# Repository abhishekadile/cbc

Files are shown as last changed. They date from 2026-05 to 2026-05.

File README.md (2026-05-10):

# Multispectral CBC Image Acquisition System

This is a complete full-stack embedded systems project for capturing multispectral CBC (Complete Blood Count) imagery using a Raspberry Pi and an InnovaMaker IMX296 global shutter camera. 

> **Disclaimer:** This is a prototype/research image acquisition system. It does not provide medical diagnosis and is not for clinical use. An AI analysis module is planned for future versions.

## 🚀 Features
- **Hardware Integration**: Controls InnovaMaker IMX296 MIPI global shutter camera.
- **Data Management**: Robust directory structure for scan sessions ensuring no lost data.
- **User Interface**: Modern React/Vite-based investor demo dashboard.
- **Extensibility**: Hardware Abstraction Layers (HAL) for future microcontrollers, XY stages, Z focus actuators, and multispectral LED channels.

## 📦 Supported Hardware
- **Current**: Raspberry Pi + InnovaMaker IMX296 MIPI camera
- **Planned**: XY Stage, Z Focus Actuator, Multispectral LED Channels, RP2040/STM32 timing controller

---

## 🛠️ Step-by-Step Setup Guide for Raspberry Pi

Follow these exact steps to set up the software on a fresh Raspberry Pi.

### 1. Initial Raspberry Pi Configuration
1. Flash standard **Raspberry Pi OS (64-bit)** to an SD card using the Raspberry Pi Imager.
2. Boot the Pi, connect it to your local Wi-Fi, and enable SSH.
3. Connect the InnovaMaker IMX296 FPC cable to the CSI port on the Raspberry Pi.
4. Open the boot configuration file to enable the camera overlay:
   ```bash
   sudo nano /boot/firmware/config.txt
   ```
5. Add the following line at the end of the file:
   ```text
   dtoverlay=imx296
   ```
6. Save (`Ctrl+O`, `Enter`) and exit (`Ctrl+X`), then reboot:
   ```bash
   sudo reboot
   ```

### 2. Verify Hardware with Libcamera
After rebooting, test that the system recognizes the camera and the driver is loaded using the standard Raspberry Pi tools:
```bash
rpicam-hello -t 5000
rpicam-still -o test.jpg
```

### 2. Software Installation
Once the Pi has rebooted, open a terminal (or SSH into it) and run the one-line bootstrap script. This script will install Git, curl, uv (Python dependency manager), clone this repository, and install all required system and frontend dependencies.

```bash
curl -fsSL https://raw.githubusercontent.com/abhishekadile/cbc/main/scripts/bootstrap_pi.sh | bash
```

Alternatively, you can install manually:
```bash
git clone https://github.com/abhishekadile/cbc.git ~/cbc-scanner
cd ~/cbc-scanner
bash scripts/install_pi.sh
```

---

## 💻 Running the Application

### Starting the Main Interface (UI + Backend)
To run the full stack (FastAPI backend + Vite React frontend) locally on the Pi:
```bash
cd ~/cbc-scanner
bash scripts/run_ui.sh
```
Once running, open a web browser on your laptop or Pi and navigate to:
**`http://localhost:8000`** (or use the Pi's actual IP address).

### Testing the REST API
You can verify the backend is running properly via the terminal:
```bash
curl http://localhost:8000/api/devices/status
curl -X POST http://localhost:8000/api/camera/test
curl -X POST http://localhost:8000/api/capture/single
curl http://localhost:8000/api/scans
```

### Running as a Background Service (Auto-start on Boot)
If you want the software to run automatically every time the Pi turns on:
```bash
cd ~/cbc-scanner
bash scripts/create_systemd_service.sh
sudo systemctl enable cbc-scanner
sudo systemctl start cbc-scanner
```

---

## 🔬 Command Line Utilities

We provide several command-line tools for debugging and manual control. All commands should be run from the `~/cbc-scanner` directory using `uv run`.

**1. Test Camera Connection**
Verifies that the IMX296 camera is properly detected and can be communicated with via Picamera2.
```bash
cd ~/cbc-scanner
uv run cbc-test-camera
```

**2. Capture a Single Image**
Captures exactly one image and saves it in a new scan session.
```bash
cd ~/cbc-scanner
uv run cbc-capture
```

**3. Run a Demo Multispectral Scan**
Simulates a full multispectral acquisition loop. It captures frames representing 5 wavelengths (White, 405nm, 530nm, 660nm, 850nm). *Note: until the LED board is connected, these use the ambient lighting.*
```bash
cd ~/cbc-scanner
uv run cbc-demo-scan
```

**4. Check Storage Info**
Displays the local storage base directory and a table of recently acquired scans.
```bash
cd ~/cbc-scanner
uv run cbc-storage-info
```

---

## 🔄 Updating the Software
To pull the latest changes from this GitHub repository and rebuild the environment:
```bash
cd ~/cbc-scanner
bash scripts/update_from_github.sh
```

---

## 📂 Data Storage Format
Images and scan metadata are never overwritten. They are stored chronologically in:
`data/scans/YYYY/MM/DD/scan_YYYYMMDD_HHMMSS_ID/`

Each scan directory contains:
- `raw/`: Raw, unprocessed `.png` image captures.
- `thumbnails/`: Downsampled images for the UI dashboard.
- `stitched/`: Future location for multi-grid panoramas.
- `metadata/manifest.json`: Device status, time, hardware profile, and exposure data.
- `logs/`: Diagnostic logs specific to the scan.

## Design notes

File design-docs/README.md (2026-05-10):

# CBC Multispectral Imaging System Design Documentation

This is a research and engineering prototype for a multispectral CBC image acquisition system. It is not for diagnosis, treatment, or clinical use.

## Folder Structure Guide

This documentation is organized into four main pillars that map directly to the system's architecture and development lifecycle:

### 1. `hardware/`
Contains the physical design of the CBC scanner. It is split into two tracks:
- **`prototype/`**: Focuses on rapid iteration. It details the 3D-printing strategy, manual assembly guides, and off-the-shelf components required to build the first functional unit. The goal here is proving the optical path and software integration.
- **`production/`**: Focuses on reliability and scaling. It outlines the transition to rigid materials, precision linear guides, and the engineering requirements for a known-volume fluid cartridge necessary for absolute cell concentration calculations.

### 2. `embedded-software/`
Details the software running directly on the hardware (the Raspberry Pi). This folder covers:
- The tech stack (Python, FastAPI, `uv`, `libcamera`/`Picamera2`).
- How the device orchestrates the capture sequence, including multispectral LED synchronization and motor control.
- The precise data schema (`manifest.json`) used to package images and metadata into a "Scan Session" before sending it to the cloud or AI pipeline.

### 3. `AI/`
Outlines the entire data science and machine learning workstream. This is the brain of the system, responsible for counting and classifying cells:
- **Model Strategy**: Deciding which architectures to use (e.g., YOLO11-seg for detection, U-Net for precise segmentation, EfficientNet for classification).
- **Pretraining & Data**: How public datasets are used to bootstrap models before fine-tuning on device-specific images.
- **Computer Vision (CV) Pipeline**: The classical algorithms (thresholding, watershed) used for immediate object detection, image quality control, and generating pseudo-labels.
- **Labeling & Evaluation**: The strict workflow for human-in-the-loop annotation and the statistical metrics used to prove accuracy.

### 4. `cloud/`
Describes the off-device architecture needed to scale the project. While the scanner is designed to be "local-first," this folder covers:
- **Data Management**: How scan sessions are securely uploaded and stored in object storage (e.g., S3).
- **Fleet & Model Registries**: Tracking active devices in the field and managing over-the-air updates for newly trained AI models.
- **Experiment Tracking**: The infrastructure (like MLflow) used by researchers to track model training runs and dataset versions.

## Build Phases

The project will follow these sequential build phases:

1. **Prototype imaging system**: Build the initial 3D-printed hardware, integrate the IMX296 camera, and establish basic control.
2. **CV-first segmentation**: Implement classical computer vision to detect objects and create pseudo-labels.
3. **AI pretraining and fine-tuning**: Pretrain models on public datasets and fine-tune on device-captured images.
4. **Hybrid AI/CV pipeline**: Integrate both approaches for robust counting and quality control.
5. **Production hardware and cartridge**: Transition to a rigid frame, controlled cartridge, and repeatable optical path.
6. **Cloud scaling and data management**: Implement cloud uploads, scan dashboards, and a model registry.

## Prototype Goals

The first prototype goal is *not* clinical accuracy. The initial objectives are to:
- capture clear microscope images
- capture 5 to 10 overlapping images
- stitch them together
- segment visible objects
- count objects
- create a dataset loop
- compare CV counts, AI counts, and reviewed labels

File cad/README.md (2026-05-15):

# CBC Microscope Prototype CAD

This `cad/` system contains Fusion-oriented Python scripts for the custom printed parts and simplified assemblies for the CBC microscope prototype.

Design policy:

- Bought precision parts stay bought: optics, rails, lead screws/nuts, boards, screws, inserts, motors, and drivers.
- Printed parts are modular bolt-together components, not a monolithic frame.
- Manual XY is the first assembly variant; NEMA17 motorized XY is optional.
- The optical datum is the sensor plane. For the finite objective path, objective shoulder to sensor plane is held at `160.0 mm`.
- Unresolved vendor geometry remains parameterized and uses slots or placeholders.
- No arbitrary shell execution, subprocess command runner, or network code is present in this CAD tree.

Key commands from the repo root:

```powershell
python -m cad.scripts.tools.build_all_parts
python -m cad.scripts.tools.build_all_assemblies
python -m cad.scripts.tools.build_stage1
python -m pytest cad/tests
```

`build_all_parts`, `build_all_assemblies`, and `build_stage1` are safe offline commands. They build deterministic specs/reports and do not create manufacturing STL/STEP files outside Fusion.

Fusion bridge smoke tests assume the existing local MCP/Fusion bridge is active at:

```text
http://127.0.0.1:8765
```

Stage 1 generated naming follows:

- Native assembly: `cbc_stage1_static_optical_stack_r001.f3d`
- STEP part: `cbc_slide_holder_r001.step`
- STL part: `cbc_slide_holder_r001.stl`

## Real Fusion Exports vs Offline Specs

Only files generated inside Autodesk Fusion through `ExportManager` should be treated as printable/manufacturing CAD.

Offline Python runs may write deterministic `.non_printable_spec.json` files for validation and CI. Those files are not STL/STEP manufacturing outputs.

The first real printable Fusion part implemented is:

```powershell
python -m cad.scripts.parts.cbc_slide_holder
```

Run that command from Fusion's Python environment, or run the script through Fusion's Scripts and Add-Ins workflow. When Fusion is live, it creates a separate component/body named `cbc_slide_holder_r001` and exports:

- `cad/exports/stl/cbc_slide_holder_r001.stl`
- `cad/exports/step/cbc_slide_holder_r001.step`

When run outside Fusion, the same command writes only a non-printable JSON spec and does not claim to create printable CAD.

For the full Stage 1 export set, run this from Fusion's Python environment:

```powershell
python -m cad.scripts.tools.export_stage1
```

Outside Fusion, `export_stage1` and `export_all` refuse with a `RuntimeError` and do not write placeholder manufacturing files.

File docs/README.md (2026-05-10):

# CBC Project Documentation Guide

This `docs/` folder organizes the project into four workstreams:

1. **Hardware** - mechanical, optical, motion, cartridge, and production design.
2. **Embedded Software** - Raspberry Pi, camera control, LED control, motion control, and device orchestration.
3. **AI** - model pretraining, dataset organization, computer vision, and final AI/CV pipeline.
4. **Cloud** - storage, APIs, dashboards, training infrastructure, model registry, and future remote device management.

The root `README.md` should remain the quick-start guide for running the current repo. This folder is for deeper engineering plans, design decisions, and implementation roadmaps.

## Folder structure

```text
docs/
  README.md
  hardware/
    README.md
    prototype/
      README.md
      prototype-spec.md
      prototype-product-list.md
    production/
      README.md
      production-spec.md
      production-product-list.md
  embedded-software/
    README.md
  AI/
    README.md
    01-model-strategy.md
    02-pretraining-plan.md
    03-computer-vision-system.md
    04-final-ai-cv-pipeline.md
  cloud/
    README.md
```

## Build order

### Phase 1: Prototype imaging system

Goal: prove that the device can capture clear microscope images, capture a small number of overlapping fields, and stitch 5 to 10 images together.

Primary docs:

- `hardware/prototype/prototype-spec.md`
- `hardware/prototype/prototype-product-list.md`
- `embedded-software/README.md`
- `AI/03-computer-vision-system.md`

### Phase 2: AI dataset and pretraining

Goal: prepare public datasets, normalize labels, train a pretrained image model on blood-cell microscopy data, and fine-tune with images captured from this device.

Primary docs:

- `AI/01-model-strategy.md`
- `AI/02-pretraining-plan.md`

### Phase 3: Hybrid CV plus neural model

Goal: use classical computer vision to generate candidate masks, coordinates, and pseudo-labels, then use reviewed labels to train the neural model.

Primary docs:

- `AI/03-computer-vision-system.md`
- `AI/04-final-ai-cv-pipeline.md`

### Phase 4: Production hardware direction

Goal: evolve from a mostly 3D-printed prototype to a controlled cartridge, more rigid optical path, calibrated motion, and repeatable image acquisition.

Primary docs:

- `hardware/production/production-spec.md`
- `hardware/production/production-product-list.md`

### Phase 5: Cloud and scaling

Goal: support remote data upload, experiment tracking, model registry, training jobs, dashboarding, and future device fleet management.

Primary docs:

- `cloud/README.md`

## Current principle

The first milestone is not clinical CBC accuracy. The first milestone is engineering validation:

- capture clear images,
- capture multiple nearby images,
- stitch fields together,
- segment visible cell-like objects,
- create a repeatable dataset loop,
- compare CV counts, model counts, and reviewed labels.

This project is a research and engineering prototype. It is not for diagnosis, treatment, or clinical decision-making.

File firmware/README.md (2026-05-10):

# Firmware

This directory will contain the C/C++ firmware for the future timing controller (e.g., STM32, RP2040) used to control the XY stage, Z focus, and multispectral LEDs.

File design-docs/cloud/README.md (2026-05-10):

# Cloud Architecture

This document describes the cloud infrastructure required to scale data collection, manage a fleet of prototype devices, and orchestrate model training.

*Important Note: This is an engineering prototype system. There are no clinical use claims. The data handled is for research and development purposes only. However, future architectures will need to observe HIPAA guidelines if transitioning to human clinical trials.*

## System Philosophy

- **Local-first system**: The scanner must be capable of completing a scan, running local CV preprocessing, and saving data without an active internet connection. The cloud is an enhancement, not a strict dependency for operation.
- **Optional cloud sync**: When connected to Wi-Fi, the device can background-upload scan sessions to cloud storage.

## Key Components

- **Storage**: Highly scalable object storage for millions of raw TIFF/JPEG images.
- **Dashboard**: A web portal for engineers and researchers to view uploaded scans, verify image quality, and manage devices.
- **Training Data Repository**: A centralized, version-controlled repository where data is formatted for PyTorch/Ultralytics consumption.
- **Experiment Tracking**: A central server logging loss curves, metrics, and configs for every AI training run.
- **Model Registry**: A version-controlled storage bin for compiled AI models (`.pt`, `.onnx`, or `.tflite`).
- **Device Registry**: A database tracking every active scanner in the field, its MAC address, current IP, hardware version, and deployed model version.
- **Access Control**: Role-Based Access Control (RBAC) ensuring only authorized engineers can trigger remote updates or access datasets.
- **Security**: TLS for all API traffic, signed URLs for direct-to-storage image uploads.

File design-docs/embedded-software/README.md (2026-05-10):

# Embedded Software

The embedded software runs on the Raspberry Pi and acts as the brain of the acquisition hardware. It orchestrates the camera, the lighting, the motion stage, and the data packaging.

## Core Responsibilities

- **Raspberry Pi as Acquisition Controller**: The Pi handles all high-level scheduling, file system operations, and network communication.
- **Camera Control**: Interfaces with the IMX296 sensor via `Picamera2` or `libcamera`, configuring exposure, gain, and format.
- **LED Control**: Toggles GPIO pins to control the multispectral LED array, ensuring the correct wavelength is active during exposure.
- **Future XY/Z Motion Control**: Interfaces with stepper motor drivers (via GPIO or I2C) to move the stage for stitching and adjust focus.
- **Scan Session Manager**: Orchestrates the multi-step process of capturing a full slide (move stage -> set LED -> capture -> next wavelength -> next position).
- **REST API**: Exposes endpoints (via FastAPI) to start, stop, and configure scans.
- **Local UI**: Serves a local React dashboard for the user operating the machine.
- **Metadata**: Collects hardware state (temperature, exposure settings) and packages it with the images.
- **Logs**: Maintains detailed diagnostic logs for troubleshooting.

## Future Microcontroller Option
As the system scales to closed-loop motors and microsecond-level LED pulsing, the Raspberry Pi's non-real-time Linux OS may introduce jitter. Future architectures will delegate real-time hardware IO to an attached microcontroller (like an RP2040 or STM32), which will communicate with the Pi via Serial/I2C.

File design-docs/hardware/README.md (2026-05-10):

# Hardware Architecture

The CBC scanner hardware is designed to evolve from an accessible, easily iteratable 3D-printed prototype to a robust, precisely calibrated production system.

## System Purpose
The primary purpose of the hardware is to acquire high-resolution, multispectral images of biological samples (specifically blood cells) with sufficient clarity and consistency to enable automated computer vision and AI-based counting/classification.

## Prototype vs. Production Philosophy
- **Prototype**: Focuses on accessibility, rapid iteration, and software integration. It uses off-the-shelf components, standard microscope slides, and 3D-printed brackets where possible. The primary goal is capturing 5-10 overlapping images to prove the stitching and baseline segmentation pipeline.
- **Production**: Focuses on stability, repeatability, and quantitative accuracy. It will transition to a rigid chassis (sheet metal/machined aluminum), precision linear guides, and a custom *known-volume* cartridge necessary for calculating absolute cell concentrations.

## Subsystem Descriptions

- **Optics**: A compound microscope optical path utilizing standard objectives (e.g., 10X or 40X Plan Achromatic) to achieve the necessary magnification and flat field of view.
- **Camera**: Raspberry Pi acting as the host for an InnovaMaker IMX296 global shutter camera. Global shutter is critical to prevent motion blur during continuous scanning or under pulsed illumination.
- **Illumination**: A multispectral LED array (e.g., 405nm, 470nm, 530nm, 660nm) coupled with a diffuser to provide uniform transmitted or reflected light.
- **Slide/Cartridge Holder**: A mechanical stage to securely hold the sample. The prototype uses standard glass slides; production will use a custom cartridge.
- **XY Stage**: Enables scanning across the sample. The prototype uses metal rods/rails; production will use high-precision linear guides.
- **Z Focus**: Adjusts focus depth, utilizing a lead screw or fine-pitch threaded rod driven by a stepper motor.
- **Frame/Enclosure**: The structural backbone. Must block ambient light to ensure controlled multispectral capture.
- **Raspberry Pi/Electronics Mount**: Secures the compute module, motor drivers, and power distribution securely away from the optical path to manage heat.
- **Cable Routing**: Cable chains or clips to route the MIPI camera ribbon cable and motor wires, preventing snagging during stage movement.
- **Power**: A centralized power supply (e.g., 12V or 24V for motors, stepped down to 5V for the Raspberry Pi).
- **Calibration Tools**: Stage micrometers and calibration slides for mapping pixel dimensions to physical microns.

## System Block Diagram

```mermaid
flowchart LR
    LED[Multispectral LED Array] --> Diffuser[Diffuser]
    Diffuser --> Sample[Slide / Cartridge]
    Sample --> Optics[Objective / Tube Lens]
    Optics --> Camera[IMX296 Camera]
    Camera --> RPi[Raspberry Pi]
    RPi --> Storage[Local Storage / API]
    Storage --> Pipeline[AI/CV Pipeline]
```

## Mechanical Stack Diagram

```mermaid
flowchart TD
    Camera[Camera Mount] --> Optics[Optics Mount / Z-Axis]
    Optics --> Base[Main Frame]
    Sample[Slide Holder / XY Stage] --> Base
    Illumination[LED / Diffuser Mount] --> Base
```

## Assumptions
- The prototype uses normal microscope slides initially.
- The final cartridge will be engineered later.
- The prototype only needs to capture 5 to 10 overlapping images and stitch them.
- The final system will use a known volume for concentration calculations.

## Engineering Risks
- **Blur**: From external vibrations or internal motor resonances. Mitigation: Dampening feet, global shutter.
- **Poor Focus**: Drift in the Z-axis. Mitigation: Anti-backlash nuts, rigid Z-carriage.
- **Vibration**: Camera shutter or fan causing micro-vibrations.
- **Backlash**: Slop in the XY stage leading to inaccurate overlapping. Mitigation: Hardware anti-backlash nuts, software backlash compensation.
- **Uneven Illumination**: Hotspots in the light source. Mitigation: High-quality diffusers, flat-field correction in software.
- **Insufficient Magnification**: Resolution too low to differentiate cell types. Mitigation: Validate 40X objective performance.
- **Bad Image Stitching**: Failure to align overlapping regions. Mitigation: Require 40-60% overlap and rich features.
- **Object Detection False Positives**: Dust on the sensor or lens being counted as cells. Mitigation: Enclosure, software filtering based on static object detection.

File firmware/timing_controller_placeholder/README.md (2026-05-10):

# Timing Controller Placeholder

Currently using Pi direct control. This is a placeholder for the RTOS/Baremetal timing controller firmware.

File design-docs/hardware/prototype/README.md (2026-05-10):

# Prototype Hardware Navigation

This folder contains the engineering design documentation for the first iteratable prototype of the CBC multispectral scanner.

## Purpose of the Prototype
The prototype's purpose is to validate the core optical path, imaging sensors, and software pipeline using rapidly accessible components (3D printed parts and off-the-shelf hardware) before committing to expensive production tooling. 

## What the First Prototype Must Prove
The first prototype is not for clinical testing. It must prove:
1. We can capture clear, focused microscope images using the IMX296 sensor.
2. We can move the sample to capture 5 to 10 overlapping images.
3. We can successfully stitch these images together using the CV pipeline.
4. We can run baseline computer vision segmentation on the stitched result.

**Clear Note:** Fully 3D-printed XY movement is acceptable *only* for an initial proof of concept. For smoother, repeatable movement, use metal rods or linear rails (like MGN12) even in the prototype phase.

## Files in This Folder

- `prototype-spec.md`: Detailed engineering requirements, tolerances, and design decisions.
- `prototype-product-list.md`: Bill of materials with researched prices and purchase links.
- `prototype-3d-printing-plan.md`: Strategy for 3D printing, materials, and STL/CAD references.
- `prototype-assembly-guide.md`: Step-by-step assembly, alignment, and testing procedures.
- `prototype-image-assets.md`: Image management guidelines and asset inventory.
- `prototype-test-plan.md`: (Coming soon) Test procedures for validating prototype success criteria.

## Recommended Build Order

1. **Source parts**: Procure items listed in the `prototype-product-list.md`.
2. **Print parts**: Slice and print components according to `prototype-3d-printing-plan.md`.
3. **Assemble optical path**: Mount the camera and objective lens, ensuring concentric alignment.
4. **Assemble slide holder / XY stage**: Build the motion system and attach the slide carriage.
5. **Connect Pi / Camera / LED**: Wire the electronics, install heat sinks, and boot the Raspberry Pi.
6. **Capture first image**: Use a calibration slide to focus and capture a single test image.
7. **Capture 5 to 10 overlapping images**: Manually (or via stepper motors) translate the stage, ensuring 40-60% overlap.
8. **Stitch**: Run the software pipeline to stitch the grid of images.
9. **Run CV segmentation**: Verify that the pipeline can extract features from the stitched image.

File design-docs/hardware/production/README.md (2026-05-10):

# Production Hardware

This directory contains specifications and documentation for the production iteration of the CBC scanner hardware.

The focus here is on evolving the system from a rapidly iteratable prototype into a robust, manufacturable device with a controlled, known-volume imaging path.

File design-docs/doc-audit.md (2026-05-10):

# Documentation Audit

## Previous State
The initial iteration of the `design-docs/` folder established a broad structure but lacked the depth required for a true engineering package. Specifically:
- **Hardware Docs**: Read more like a high-level summary. They lacked specific part recommendations, pricing, 3D printing parameters, and clear risk mitigation strategies.
- **AI Docs**: Were generic and lacked concrete model names, dataset lists, or integration strategies.
- **Embedded & Cloud**: Only contained single `README.md` files with brief bullet points.
- **Missing Elements**: No defined tech stacks, no labeling schemas, no evaluation metrics, and no rigorous image/asset management rules.

## Improvements Made
- **Real Product & Price Research**: Replaced placeholders with real vendor links, estimated costs, and specific part names (e.g., MGN12 rails, TMC2209 drivers, AmScope 40X objectives) via the `sources/product-sources.csv` and detailed BOMs.
- **Engineering Specificity**: Expanded the hardware specs to include tolerances, failure modes, and clear logic for when to use 3D printed vs. metal parts.
- **Comprehensive AI Strategy**: Outlined specific model architectures (YOLO11-seg, U-Net, EfficientNet-B0), identified public datasets (BCCD, PBC, Raabin-WBC), and detailed a concrete active learning workflow.
- **Tech Stacks Defined**: Created `05-ai-tech-stack.md`, `embedded-stack.md`, and `cloud-stack.md` to define Python 3.11+, `uv`, PyTorch, Ultralytics, and FastAPI as the core technologies.
- **Actionable Guides**: Rewrote the 3D printing plan and assembly guides to be step-by-step engineering instructions, including print settings and heat-set insert requirements.
- **Asset Tracking**: Established an image inventory system (`sources/image-sources.csv`) to manage assets without violating copyright, favoring Mermaid diagrams where possible.

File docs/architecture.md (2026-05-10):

# Architecture

The system uses a supervisor-controller architecture.

Currently, the Raspberry Pi acts as both supervisor and controller, directly managing the camera and running the web dashboard.

In the future, the Raspberry Pi will act solely as the supervisor and image processor. A dedicated microcontroller (e.g., STM32 or RP2040) will act as the timing controller, receiving high-level commands over serial and directly driving the XY stage, Z focus, and multispectral LEDs with microsecond precision, as well as triggering the camera externally.

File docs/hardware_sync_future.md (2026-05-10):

# Future Hardware Sync

1. Pi sends high-level command (e.g., `START_GRID_SCAN`)
2. Microcontroller moves XY stage to position.
3. Microcontroller selects LED channel.
4. Microcontroller triggers camera.
5. Camera strobe output gates LED driver for perfect exposure.
6. Pi receives frame over CSI.
7. Repeat until grid is complete.

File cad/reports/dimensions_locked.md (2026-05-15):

# Locked Dimensions

## Exact / Locked
- System envelope: `200 x 200 x 300 mm` maximum.
- Stage 1 baseplate: `180 x 160 x 6 mm` with `8 mm` corner radius.
- Slide: `75.0 x 25.0 mm`.
- Slide pocket: `76.0 x 25.6 mm`, derived from slide size plus clearances.
- Viewing window: `22.0 x 12.0 mm`.
- Finite objective stack datum: objective shoulder to sensor plane = `160.0 mm`.
- RMS objective standard: `0.8 in x 36 TPI`; printed thread fit is still coupon-gated.
- Raspberry Pi Global Shutter camera: `38 x 38 mm` board, `30 x 30 mm` hole span, `2.5 mm` holes.
- Raspberry Pi 4: `85 x 56 mm` board, `58 x 49 mm` hole span, `2.7 mm` holes.
- Raspberry Pi Pico board envelope only: `51.3 x 21.0 x 3.9 mm`.
- TLC5947 board envelope only: `51.1 x 25.39 x 4.0 mm`.
- Perma-Proto Quarter policy values: `50.8 x 43.0 x 1.6 mm`, two mounting holes `35.56 mm` apart.
- Pololu 2267 NEMA17 envelope: `42.3 x 42.3 x 38.0 mm`, `5.0 mm` shaft, `31 x 31 mm` mount span.

## Corrections
- Slide pocket X was corrected from `75.5 mm` to `76.0 mm` because end clearance is applied at both slide ends.
- Perma-Proto Quarter was corrected from the earlier `55 x 44 mm` placeholder to the Adafruit 1608 policy dimensions.
- Pico and TLC5947 mounting-hole spans are not locked here; they remain unresolved unless backed by a mechanical drawing or measurement.

## Verification Notes
- Verify Raspberry Pi 4 connector keepout zones against the specific Raspberry Pi 4 revision before final enclosure design.
- The BOM/product ID for the Perma-Proto Quarter must be checked before final tray geometry; Stage 1 avoids a four-hole rectangular assumption.

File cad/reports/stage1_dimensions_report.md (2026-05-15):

# Stage 1 Dimensions Report

Stage 1 is a static optical/base assembly. It is not the final XY-motion microscope and does not freeze unresolved vendor geometry.

## Locked Geometry
- Baseplate: 180.0 x 160.0 x 6.0 mm.
- Slide pocket: 76.0 x 25.6 mm for a 75 x 25 mm slide.
- Viewing window: 22.0 x 12.0 mm.
- Pi 4 board nest: 85.5 x 56.5 mm.
- Pi 4 mount span: 58.0 x 49.0 mm.
- RPi GS camera board nest: 38.5 x 38.5 mm.
- RPi GS camera hole span: 30.0 x 30.0 mm.
- Optical axis location: X=0.0 mm, Y=12.0 mm.
- Objective shoulder to sensor plane datum: 160.0 mm.

## Corrections Applied
- Slide pocket corrected and locked at 76.0 x 25.6 mm from slide size plus end/side clearances.
- Perma-Proto Quarter dimensions corrected to the Adafruit 1608 policy values: 50.8 x 43.0 x 1.6 mm with a two-hole 35.56 mm span.

## Real Export Policy
- `build_stage1` writes reports/spec metadata and may build live Fusion geometry when run inside Fusion.
- Manufacturing STL/STEP/F3D files are written only by `export_stage1` through Fusion ExportManager.
- Offline placeholder manufacturing files are intentionally not produced.

## Assembly Warnings
- Unresolved Stage 1 optical dimensions: unresolved_dimensions.objective_amscope_40x.shoulder_d_mm, unresolved_dimensions.objective_amscope_40x.body_outer_d_mm, unresolved_dimensions.objective_amscope_40x.body_length_mm, unresolved_dimensions.stage1_optical_stack.imx296_sensor_plane_offset_from_mount_face_mm, unresolved_dimensions.stage1_optical_stack.rpi_gs_sensor_plane_offset_from_mount_face_mm, unresolved_dimensions.stage1_optical_stack.amscope_40x_objective_shoulder_geometry_mm, unresolved_dimensions.stage1_optical_stack.objective_parfocal_distance_mm

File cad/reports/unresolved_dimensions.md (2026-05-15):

# Unresolved Dimensions

- `unresolved_dimensions.camera_innomaker_imx296.board_x_mm`
- `unresolved_dimensions.camera_innomaker_imx296.board_y_mm`
- `unresolved_dimensions.camera_innomaker_imx296.board_z_mm`
- `unresolved_dimensions.camera_innomaker_imx296.mount_hole_dia_mm`
- `unresolved_dimensions.camera_innomaker_imx296.mount_hole_span_x_mm`
- `unresolved_dimensions.camera_innomaker_imx296.mount_hole_span_y_mm`
- `unresolved_dimensions.camera_innomaker_imx296.sensor_plane_offset_from_mount_face_mm`
- `unresolved_dimensions.objective_amscope_40x.shoulder_d_mm`
- `unresolved_dimensions.objective_amscope_40x.body_outer_d_mm`
- `unresolved_dimensions.objective_amscope_40x.body_length_mm`
- `unresolved_dimensions.stage1_optical_stack.imx296_sensor_plane_offset_from_mount_face_mm`
- `unresolved_dimensions.stage1_optical_stack.rpi_gs_sensor_plane_offset_from_mount_face_mm`
- `unresolved_dimensions.stage1_optical_stack.amscope_40x_objective_shoulder_geometry_mm`
- `unresolved_dimensions.stage1_optical_stack.objective_parfocal_distance_mm`
- `unresolved_dimensions.pi4_connector_keepouts.usb_ethernet_zone_mm`
- `unresolved_dimensions.pi4_connector_keepouts.usb_c_power_zone_mm`
- `unresolved_dimensions.pi4_connector_keepouts.hdmi_zone_mm`
- `unresolved_dimensions.pi4_connector_keepouts.gpio_header_zone_mm`
- `unresolved_dimensions.pico_mount.mount_hole_span_x_mm`
- `unresolved_dimensions.pico_mount.mount_hole_span_y_mm`
- `unresolved_dimensions.pico_mount.mount_hole_dia_mm`
- `unresolved_dimensions.tlc5947_mount.mount_hole_span_x_mm`
- `unresolved_dimensions.tlc5947_mount.mount_hole_span_y_mm`
- `unresolved_dimensions.tlc5947_mount.mount_hole_dia_mm`
- `unresolved_dimensions.permaproto_quarter.second_axis_mount_span_mm`
- `unresolved_dimensions.permaproto_quarter.orientation_on_tray`
- `unresolved_dimensions.nema17_pololu_2267.shaft_length_mm`
- `unresolved_dimensions.nema17_pololu_2267.pilot_boss_d_mm`
- `unresolved_dimensions.nema17_pololu_2267.pilot_boss_height_mm`
- `unresolved_dimensions.rail_system.selected_family`
- `unresolved_dimensions.rail_system.rail_hole_pitch_mm`
- `unresolved_dimensions.rail_system.rail_hole_dia_mm`
- `unresolved_dimensions.rail_system.carriage_hole_span_x_mm`
- `unresolved_dimensions.rail_system.carriage_hole_span_y_mm`
- `unresolved_dimensions.rail_system.carriage_hole_thread_mm`
- `unresolved_dimensions.lead_screw.screw_lead_mm_per_rev`
- `unresolved_dimensions.lead_screw.nut_body_x_mm`
- `unresolved_dimensions.lead_screw.nut_body_y_mm`
- `unresolved_dimensions.lead_screw.nut_body_z_mm`
- `unresolved_dimensions.lead_screw.nut_mount_hole_span_x_mm`
- `unresolved_dimensions.lead_screw.nut_mount_hole_span_y_mm`
- `unresolved_dimensions.lead_screw.nut_mount_hole_dia_mm`

These remain unresolved by design. Do not replace slots/placeholders with fixed geometry until measured or backed by reliable vendor drawings.

## Measure Before Stage 2

- InnovaMaker IMX296 board outline, mounting pattern, thickness, and sensor-plane offset.
- AmScope 40X objective shoulder geometry, body outer diameter, body length, and any printed thread compensation.
- Raspberry Pi 4 connector keepout zones for the exact board revision used.
- Raspberry Pi Pico and TLC5947 mounting-hole positions if dedicated board mounts are added.
- Perma-Proto Quarter product ID/orientation if a retained tray replaces simple slots or walls.
- Rail, carriage, T8 lead nut, and motor pilot dimensions before Stage 2 XY-motion CAD.

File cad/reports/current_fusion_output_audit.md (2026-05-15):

# Current Fusion Output Audit

The current Fusion model built through the bridge is a smoke-test / concept placeholder only.

It is not printable CAD and must not be used for assembly, manufacturing, fit checks, or procurement decisions.

Observed issues:

- The model is made from generic boxes, cylinders, and rough envelope bodies.
- It lacks real functional interfaces such as engineered mounting holes, heat-set insert bosses, board nests, pockets, cable reliefs, and controlled tolerances.
- It does not contain separate production-ready printable components with validated export boundaries.
- It does not encode actual assembly constraints or verified purchased-part interfaces.
- It includes placeholder envelopes for unresolved components, but those envelopes are not final vendor geometry.
- It should not be exported as final STL, STEP, or F3D manufacturing data.

Disposition:

- Supersede this model with the parametric Stage 1 Fusion scripts in `cad/scripts/parts/`, `cad/scripts/assemblies/`, and `cad/scripts/tools/`.
- Generate one real printable component at a time from locked YAML dimensions.
- Keep unresolved camera, objective, rail, and lead-screw dimensions in `cad/params/unresolved_dimensions.yaml` and `cad/reports/unresolved_dimensions.md`.
- Use Stage 1 only for the static microscope base, slide holder, Pi mount, camera reference mount, objective placeholder holder, and optical-axis datum.

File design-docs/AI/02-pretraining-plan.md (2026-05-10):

# Pretraining Plan

This document details the strategy for bootstrapping the AI models using public datasets before fine-tuning them on our device-specific imagery.

## Verified Dataset Sources

See `design-docs/sources/dataset-sources.csv` for full details.

- **BCCD (Blood Cell Count and Detection)**: Small dataset (364 images) with Bounding Boxes for RBC, WBC, and Platelets. Good for initial YOLO detection pipeline testing.
- **PBC (Acevedo Peripheral Blood Cells)**: Large dataset (17k+ images) for WBC sub-classification.
- **Raabin-WBC**: Comprehensive dataset with cell locations, types, and segmented nuclei/cytoplasm. Excellent for U-Net / instance segmentation pretraining.
- **BloodMNIST**: Part of MedMNIST v2. 28x28 classification dataset. Good for testing model architectures quickly, but too low-res for final production use.
- **BBBC (Broad Bioimage Benchmark Collection)**: Contains various microscopy datasets useful for general cell segmentation pretraining.

## Dataset Handling & Preprocessing

- **Detection labels**: Convert all bounding box datasets (e.g., Pascal VOC XML from BCCD) to standard YOLO format and COCO JSON format.
- **Segmentation masks**: Standardize all masks to a common format (e.g., binary PNGs where 0=background, 255=object, or indexed PNGs for multi-class).
- **Classification datasets**: Organize into standard PyTorch ImageFolder structures or use a central CSV mapping file.
- **Unlabeled datasets**: Utilize for self-supervised learning (e.g., training a DINOv2 backbone) or process through the CV pseudo-labeling pipeline.
- **RGB vs. Monochrome**: Most public datasets are RGB (stained). If our prototype uses a monochrome sensor, we must create grayscale versions of the public data during preprocessing.
- **Multispectral Device Images**: Store as aligned per-wavelength channels (e.g., a 4-channel TIFF instead of 3-channel RGB).
- **Locked Test Set**: A portion of the data (especially device-specific data) must be locked away. It must *never* be auto-labeled, pseudo-labeled, or used during any training phase.

## Proposed Dataset Structure

```
datasets/
  raw/
    public/
    internal/
  processed/
    detection/
    segmentation/
    classification/
    multispectral/
  labels/
    yolo/
    coco/
    masks/
    classification_csv/
  splits/
    train.txt
    val.txt
    test_locked.txt
  metadata/
    dataset_registry.csv
    label_schema.json
    preprocessing_config.yaml
```

## Training Stages

1. **Collect datasets**: Download from sources listed in the CSV.
2. **Verify licenses**: Ensure usage complies with MIT, CC BY 4.0, etc.
3. **Normalize labels**: Run scripts to convert everything to YOLO/COCO.
4. **Create grayscale versions**: Synthesize monochrome data from RGB stains.
5. **Train baseline detector**: Train YOLO11 on BCCD (grayscale) to prove the pipeline works.
6. **Train baseline segmenter**: Train UNet on Raabin-WBC segmentation masks.
7. **Train WBC classifier**: Train EfficientNet on the PBC dataset.
8. **Fine-tune on device images**: Freeze backbones, train on images captured by the prototype hardware.
9. **Add multispectral channels**: Modify the input layer of the models to accept N-channels instead of 1 or 3, and train on multispectral data.
10. **Active learning loop**: Deploy the model, flag uncertain predictions, have humans review them, and add them back to the training set.
11. **Evaluate on locked test set**: Perform the final benchmark.

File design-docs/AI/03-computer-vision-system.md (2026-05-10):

# Computer Vision System

This document describes the classical Computer Vision (CV) algorithms used for initial object detection, quality control, and pseudo-label generation. These algorithms provide immediate utility without requiring labeled training data.

## Recommended Packages
- `OpenCV` (`cv2`)
- `scikit-image` (`skimage`)
- `NumPy`, `SciPy`, `pandas`
- `tifffile` / `imageio` (for handling multi-page TIFFs or multispectral stacks)
- `napari` or `FiftyOne` / `CVAT` / `Label Studio` (for visual review of CV outputs)

## Concrete Pipeline Algorithms

### 1. Preprocessing & Enhancement
- **Flat-field correction**: Corrects for uneven illumination (vignetting) caused by the LED/diffuser setup. `Corrected = (Raw - DarkFrame) / (FlatField - DarkFrame)`.
- **Dark-frame subtraction**: Removes fixed-pattern sensor noise.
- **Filtering**: Apply Gaussian, Median, or Bilateral filtering to reduce noise while preserving edges.
- **Contrast Enhancement**: Use CLAHE (Contrast Limited Adaptive Histogram Equalization) to normalize contrast across different imaging sessions.

### 2. Segmentation & Detection
- **Thresholding**: Otsu's method for global thresholding, or Adaptive Thresholding for images with varying background illumination.
- **Edge Detection**: Canny edge detection (useful for finding sharp boundaries of cells).
- **Morphological Operations**: Opening (removes small noise) and Closing (fills small holes inside cells).
- **Instance Separation**: 
    - Compute the **Distance Transform**.
    - Apply **Watershed Segmentation** using local maxima as markers to split clumped cells.
- **Feature Extraction**:
    - **Connected Components** / **Contour Detection**.
    - **Blob Detection** (Laplacian of Gaussian - LoG).
    - *Optional Baseline*: Hough circles (only useful for perfectly spherical, non-clumped RBCs).

### 3. Filtering & Quality Control
- **Shape Filtering**: Filter detected contours based on Area, Perimeter, Circularity, Eccentricity, and Aspect Ratio to reject artifacts (dust, scratches).
- **Focus Metric**: Calculate the Variance of the Laplacian. Images falling below a certain threshold are rejected as "blurry".
- **Brightness/Saturation Checks**: Reject images that are entirely black (LED failed) or entirely white (overexposed).

## Multispectral Processing Strategy
1. **Capture**: The hardware captures the same FOV under different LED wavelengths.
2. **Registration**: Align the channels to correct for micro-vibrations between captures. Use Phase Correlation for translations, or ECC (Enhanced Correlation Coefficient) alignment.
3. **Stacking**: Create a multi-channel NumPy array.
4. **Feature Engineering**: Compute wavelength contrast ratios (e.g., `(Ch1 - Ch2) / (Ch1 + Ch2)`) to highlight specific cell structures that absorb specific wavelengths.
5. **Selection**: Choose the best wavelength (or computed ratio) to run the segmentation pipeline on for specific object types.

## Pseudo-Labeling Export
The CV pipeline acts as the first "annotator". It exports:
- Bounding boxes in **YOLO format**.
- Polygons in **COCO format**.
- Binary **Segmentation Masks**.
- **CSV** with center coordinates and calculated shape metrics.
- **Confidence/Quality flags**: E.g., "High Confidence" if the object is perfectly circular and isolated; "Low Confidence" if it was split by the watershed algorithm.

**Human Review Queue**: Low-confidence CV predictions are pushed to Label Studio/CVAT for human correction before being fed into the AI training loop.

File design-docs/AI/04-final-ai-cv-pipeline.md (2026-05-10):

# Final AI/CV Pipeline

This document defines the integrated production pipeline, moving from hardware capture through to the final count and dataset loop.

## Pipeline Architecture

```mermaid
flowchart TD
    Capture[Hardware Capture] --> Metadata[Attach Metadata]
    Metadata --> Preprocess[Flat-field / Denoise]
    Preprocess --> Register[Register Wavelengths]
    Register --> Stitch[Stitch Overlapping FOVs]
    
    Stitch --> CVSegment[CV Segmentation]
    Stitch --> AISegment[AI Segmentation & Classify]
    
    CVSegment --> Disagree[Disagreement Detection]
    AISegment --> Disagree
    
    Disagree -- Agreement High --> Count[Calculate Count]
    Disagree -- Agreement Low --> LabelQueue[Human Review Queue]
    
    LabelQueue --> DatasetUpdate[Dataset Update]
    DatasetUpdate --> Retrain[Retrain Models]
    Retrain --> Registry[Model Registry]
    Registry -. Deploy .-> AISegment
    
    Count --> QC[QC / Error Analysis]
```

## Stage Definitions

1. **Acquisition**: The Raspberry Pi captures raw sensor data.
2. **Metadata**: The system logs timestamp, exposure, focus score, wavelength, and stage coordinates into a `manifest.json`.
3. **Multispectral Capture**: Multiple frames are captured at different wavelengths without moving the stage.
4. **Registration**: Micro-shifts between multispectral frames are corrected.
5. **Stitching**: Overlapping fields of view (FOVs) are stitched into a single large mosaic image to prevent double-counting cells on the borders.
6. **Preprocessing**: Dark-frame and flat-field corrections are applied.
7. **CV Segmentation**: Classical thresholding and watershed run to provide a robust baseline detection.
8. **Neural Segmentation & Classification**: The fine-tuned AI model (e.g., YOLO11-seg or UNet) segments and classifies the objects.
9. **Disagreement Detection**: The system compares the CV bounding boxes against the AI bounding boxes. Large discrepancies trigger a review flag.
10. **Counting**: 
    - *Prototype*: The system simply counts the total number of visible objects per stitched field.
    - *Production*: The system converts the raw count to a clinical concentration metric (e.g., cells/μL) using the known imaged volume of the engineered cartridge. We do *not* directly predict the final CBC count with an end-to-end model; the primary count is strictly derived from segmented objects.
11. **Quality Control**: The count is checked against physiological limits to flag catastrophic failures.
12. **Pseudo-label Update**: High-confidence predictions where CV and AI agree are automatically added to the dataset as pseudo-labels.
13. **Active Learning (Label Queue)**: Low-confidence AI predictions or high CV/AI disagreement cases are pushed to a dashboard for human review and correction.
14. **Retraining**: The model is periodically retrained on the growing dataset.
15. **Model Registry**: The newly trained model is versioned and staged for over-the-air deployment back to the hardware.
16. **Future Cartridge Calibration**: The pipeline will integrate with physical calibration targets inserted into the machine to ensure the volume calculations remain accurate.

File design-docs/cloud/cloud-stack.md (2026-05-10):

# Cloud Tech Stack

This document defines the backend technologies used for managing the data pipeline off-device.

## Prototype Stack (Getting Started)

During the early prototype phase, "cloud" infrastructure might just run locally on a developer's laptop or a single local server to avoid AWS/GCP costs.
- **Storage**: Local filesystem mapping.
- **Database**: SQLite (easy to manage, single file).
- **API**: FastAPI (Python).
- **Dashboard**: Simple React frontend talking to the FastAPI backend.
- **Path to scaling**: Move images to an S3-compatible local server like MinIO if needed.

## Scaling Stack (Production Deployment)

When deploying multiple devices and training large models, the stack moves to managed services.
- **Object Storage**: AWS S3 or GCP Cloud Storage. Devices use *Signed URLs* to upload images directly to the bucket, bypassing the API server bottleneck.
- **Relational Database**: PostgreSQL (for the Device Registry, User Auth, and Scan Metadata).
- **Experiment Tracking**: MLflow or Weights & Biases (W&B) hosted centrally.
- **Containerization**: Docker for all API and Dashboard services.
- **CI/CD**: GitHub Actions to run tests, build Docker images, and trigger model evaluations.
- **Model Registry**: MLflow Model Registry or HuggingFace Hub (Private) to version control `.onnx` models.
- **Background Workers**: Celery or RabbitMQ/Redis to handle heavy background tasks (like cloud-side image stitching or dataset compilation).

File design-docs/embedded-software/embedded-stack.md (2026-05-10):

# Embedded Tech Stack

This document defines the software stack running on the Raspberry Pi.

## Core Stack
- **Language**: Python 3.11+
- **Environment**: `uv` for lightning-fast dependency management and isolated virtual environments.
- **Web Server**: `FastAPI` (running via Uvicorn). Provides high-performance async REST APIs for the local UI.
- **Camera API**: `Picamera2` (the official Python library built on top of `libcamera`). Critical for accessing low-level sensor controls of the IMX296.
- **Data Validation**: `pydantic` for strictly typing API payloads and metadata manifests.
- **Local Database**: `SQLite` (optional, for tracking scan history locally before cloud upload).
- **Local Preprocessing**: `OpenCV` (`cv2-python-headless`) for running fast local checks like the focus metric before saving the image.
- **Service Management**: `systemd` to ensure the FastAPI server and hardware daemons start automatically on boot.

## Hardware IO Libraries
- **GPIO Control**: `gpiozero` or `RPi.GPIO` for toggling LED drivers and basic limit switches.
- **I2C/SPI**: `smbus2` or `spidev` for communicating with potential external ADCs, DACs, or motor controllers.

## Future Architecture (Real-Time Control)
If precise microsecond timing is needed for strobing LEDs in sync with the global shutter:
- **Microcontroller Option**: Raspberry Pi Pico (RP2040) or STM32.
- **Microcontroller Firmware**: Written in C/C++ (PlatformIO/Arduino) or MicroPython.
- **Communication Protocol**: Standard UART serial or I2C between the Pi and the MCU.

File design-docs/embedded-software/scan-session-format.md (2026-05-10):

# Scan Session Format

All data captured during a single scanning operation must be structured uniformly to allow the AI pipeline and cloud dashboard to parse it without ambiguity.

## Folder Structure

When a scan is initiated, a new directory is created using the current timestamp and a unique ID.

```
data/
  scans/
    YYYY/
      MM/
        DD/
          scan_YYYYMMDD_HHMMSS_ID/
            raw/             # Unprocessed TIFFs or Bayer RAW files directly from sensor
            thumbnails/      # 8-bit JPEGs heavily compressed for quick UI rendering
            stitched/        # The final mosaic image (if computed locally)
            metadata/
              manifest.json  # The single source of truth for this scan
            logs/            # Diagnostic text logs (errors, warnings, timing)
```

## `manifest.json` Schema

The manifest file binds the images to the hardware state at the moment of capture. It must adhere to the following schema:

```json
{
  "scan_id": "scan_20260510_143000_abc123",
  "timestamp": "2026-05-10T14:30:00Z",
  "device_id": "pi4_proto_001",
  "hardware_version": "v1.0-prototype",
  "software_version": "1.2.4",
  "camera": {
    "model": "IMX296",
    "exposure_us": 15000,
    "analog_gain": 2.0
  },
  "optics": {
    "objective": "AmScope_40X_Plan",
    "tube_length_mm": 160
  },
  "images": [
    {
      "filename": "raw/img_001_405nm.tiff",
      "wavelength_nm": 405,
      "tile_index": {"row": 0, "col": 0},
      "stage_position_mm": {"x": 12.5, "y": 8.0, "z": 0.4},
      "focus_score_laplacian": 450.2
    },
    {
      "filename": "raw/img_001_530nm.tiff",
      "wavelength_nm": 530,
      "tile_index": {"row": 0, "col": 0},
      "stage_position_mm": {"x": 12.5, "y": 8.0, "z": 0.4},
      "focus_score_laplacian": 410.8
    }
  ]
}
```

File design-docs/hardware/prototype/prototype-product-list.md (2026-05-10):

# Prototype Product List

This document details the exact components required for the prototype build, including researched pricing and links.
*Prices verified as of May 10, 2026. Do not invent unavailable prices.*

| Subsystem | Part (Qty) | Purpose | Selected Product | Price | Vendor Link | Image | Notes |
| :--- | :--- | :--- | :--- | :--- | :--- | :--- | :--- |
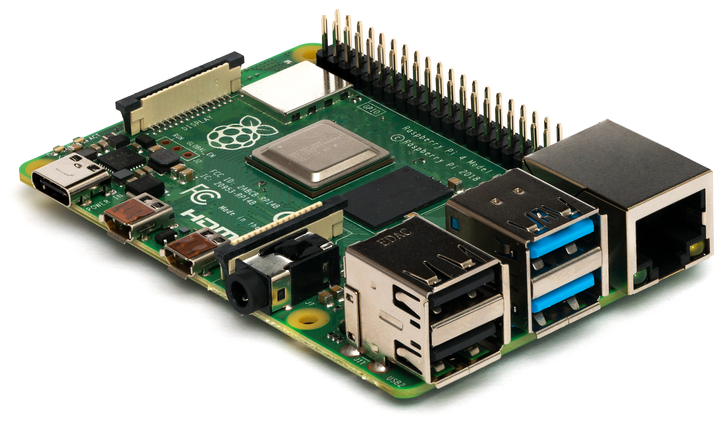
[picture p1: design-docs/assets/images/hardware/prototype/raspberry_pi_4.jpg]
| Compute | Raspberry Pi 4 (1) | Control & Capture | Raspberry Pi 4 (4GB) | $55.00 | [Adafruit/PiShop](https://www.raspberrypi.com/products/raspberry-pi-4-model-b/) |  | **High**: Need adequate cooling. |
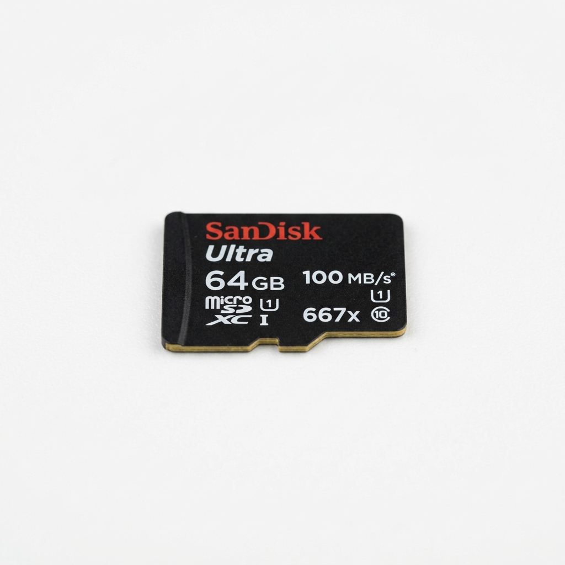
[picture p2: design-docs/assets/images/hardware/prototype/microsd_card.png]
| Compute | MicroSD Card (1) | OS Storage | Generic 32GB Class 10 | $8.00 | [Amazon Search](https://www.amazon.com/s?k=32GB+Class+10+MicroSD+Card) |  | **High**: High endurance preferred. |
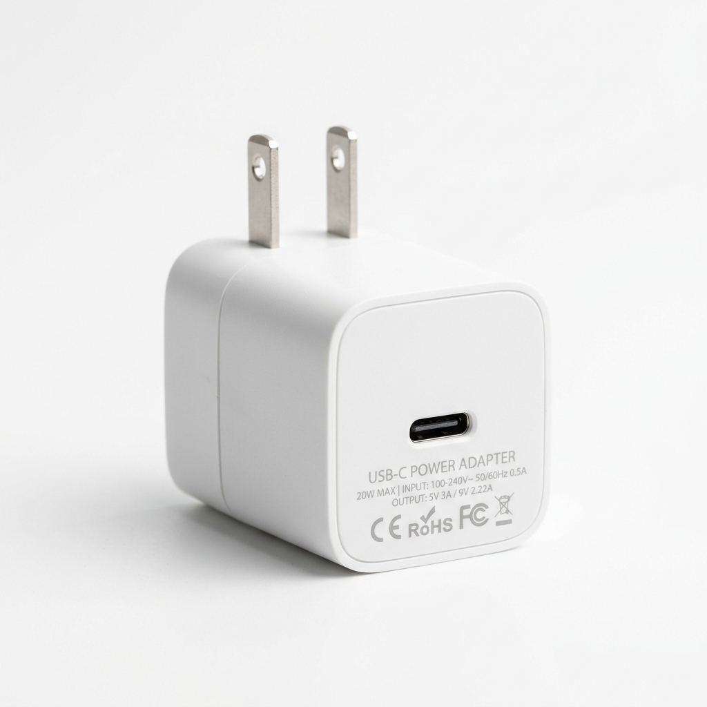
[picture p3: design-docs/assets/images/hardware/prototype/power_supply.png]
| Compute | Power Supply (1) | Power RPi | Generic 5V 3A | $8.00 | [Amazon Search](https://www.amazon.com/s?k=Raspberry+Pi+4+Power+Supply) |  | **High** |
| Camera | IMX296 Camera (1) | Image Sensor | InnovaMaker IMX296 | $60.00 | [InnovaMaker](https://www.inno-maker.com/product/imx296-camera-module/) |  | **Critical**: Global shutter required. |
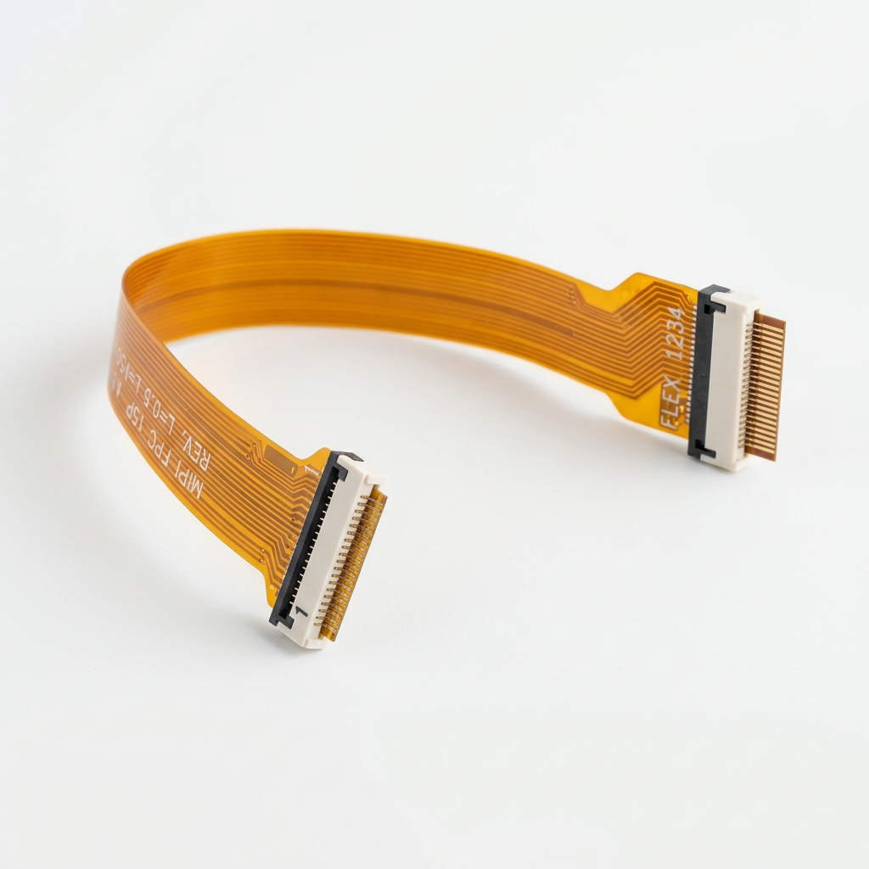
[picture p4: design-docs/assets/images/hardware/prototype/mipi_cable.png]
| Camera | MIPI Cable (1) | Data connection | Included with camera | $0.00 | - |  | **High**: Pi 5 uses different pitch. |
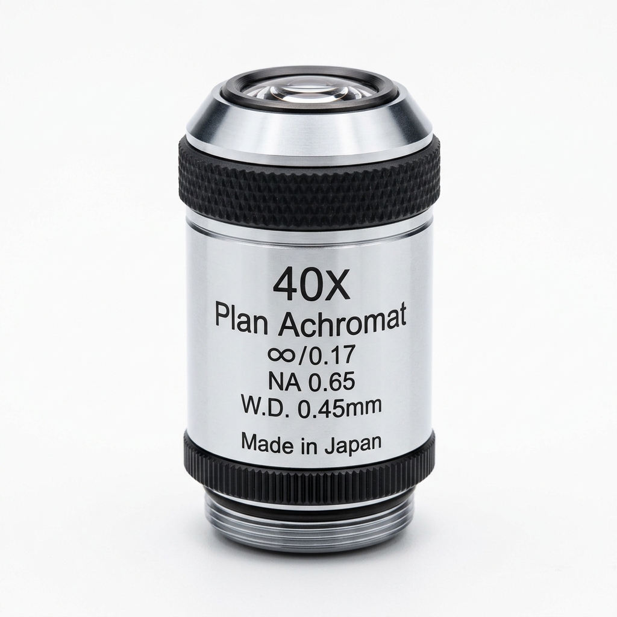
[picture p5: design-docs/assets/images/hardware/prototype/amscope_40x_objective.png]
| Optics | 40X Objective (1) | Magnification | AmScope Standard 40X | $45.00 | [AmScope](https://amscope.com/products/40x-plan-achromatic-objective-lens-with-knurled-ring) |  | **Critical**: "Plan" is needed for flat fields. |
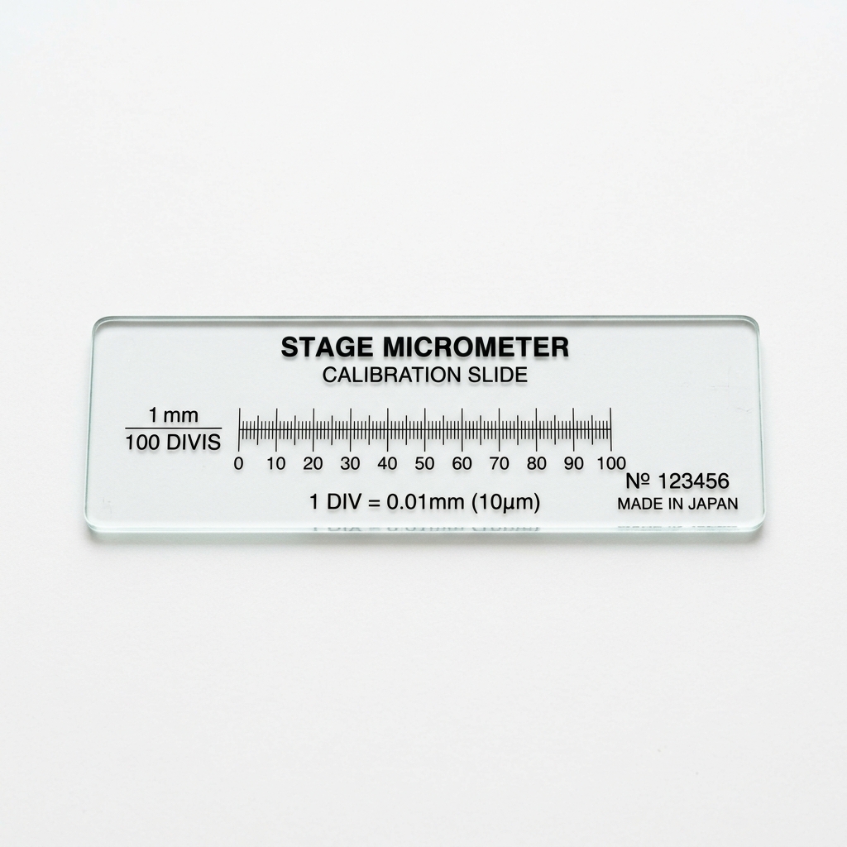
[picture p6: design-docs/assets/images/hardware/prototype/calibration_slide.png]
| Optics | Calibration Slide (1) | Scale reference | Printed Grid (Not rec) | $20.00 | [AmScope](https://amscope.com/products/microscope-stage-calibration-slide-for-usb-camera-0-01mm-stage-micrometer) |  | **Medium**: Essential for measuring FOV. |
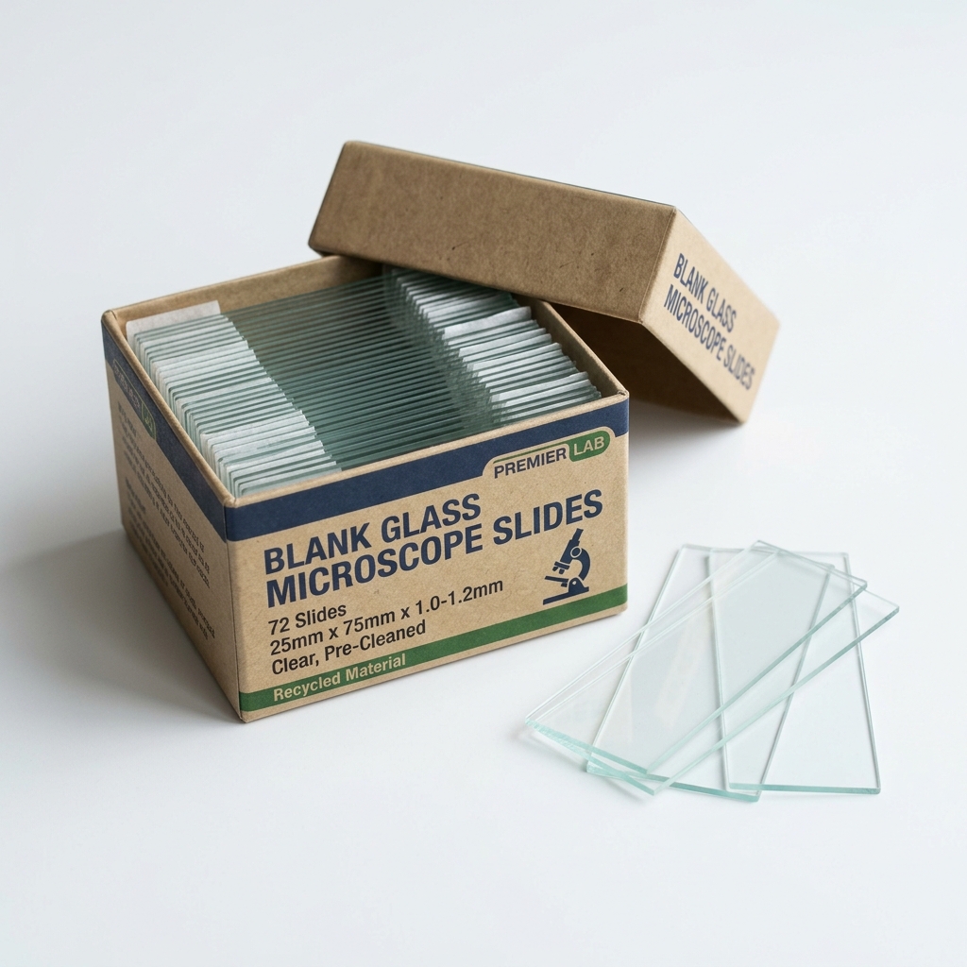
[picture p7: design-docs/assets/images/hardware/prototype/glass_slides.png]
| Sample | Glass Slides (1) | Hold sample | Standard box of 72 | $10.00 | [Amazon Search](https://www.amazon.com/s?k=Blank+Microscope+Glass+Slides+72+pieces) |  | **High** |
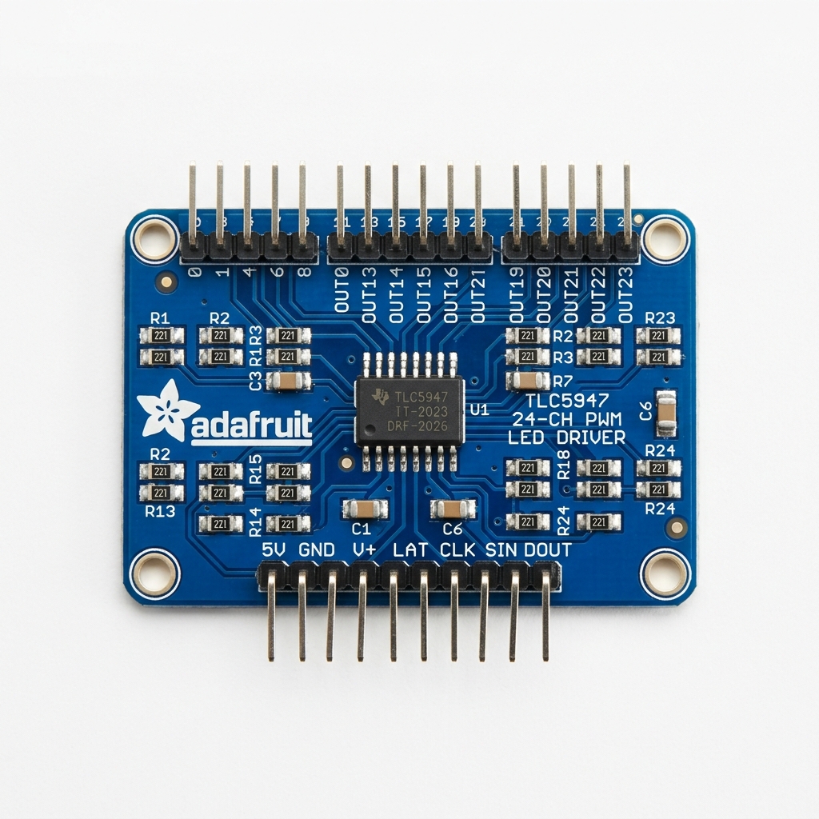
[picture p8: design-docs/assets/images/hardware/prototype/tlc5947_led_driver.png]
| Illumination/Control | LED Driver Board (1) | PWM LED Control | Adafruit TLC5947 | $17.50 | [Adafruit](https://www.adafruit.com/product/1429) |  | **Critical**: Version 1 multispectral LED driver. 24 constant-current sink channels with 12-bit PWM. Suitable for low-power LEDs, not 1W/3W high-power LEDs. |
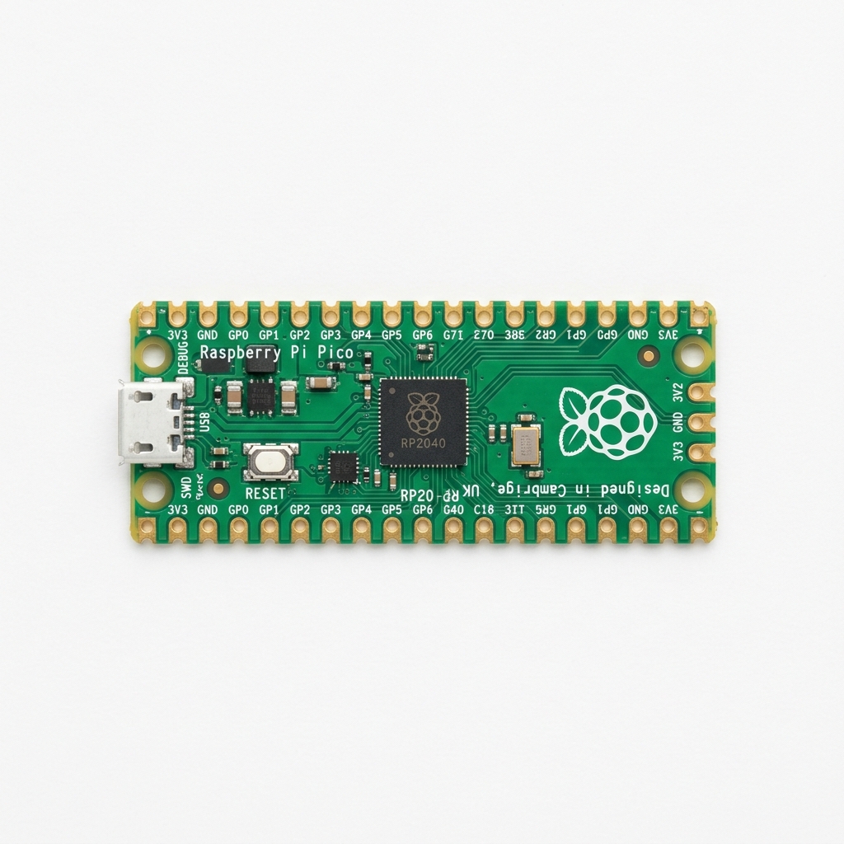
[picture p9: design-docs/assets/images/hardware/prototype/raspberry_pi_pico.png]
| Illumination/Timing | Microcontroller (1) | LED timing controller | Raspberry Pi Pico RP2040 | $4.00 | [Adafruit](https://www.adafruit.com/product/4864) |  | **High**: High-level orchestration on RPi, lower-jitter LED timing on Pico. Communicates via USB serial. |
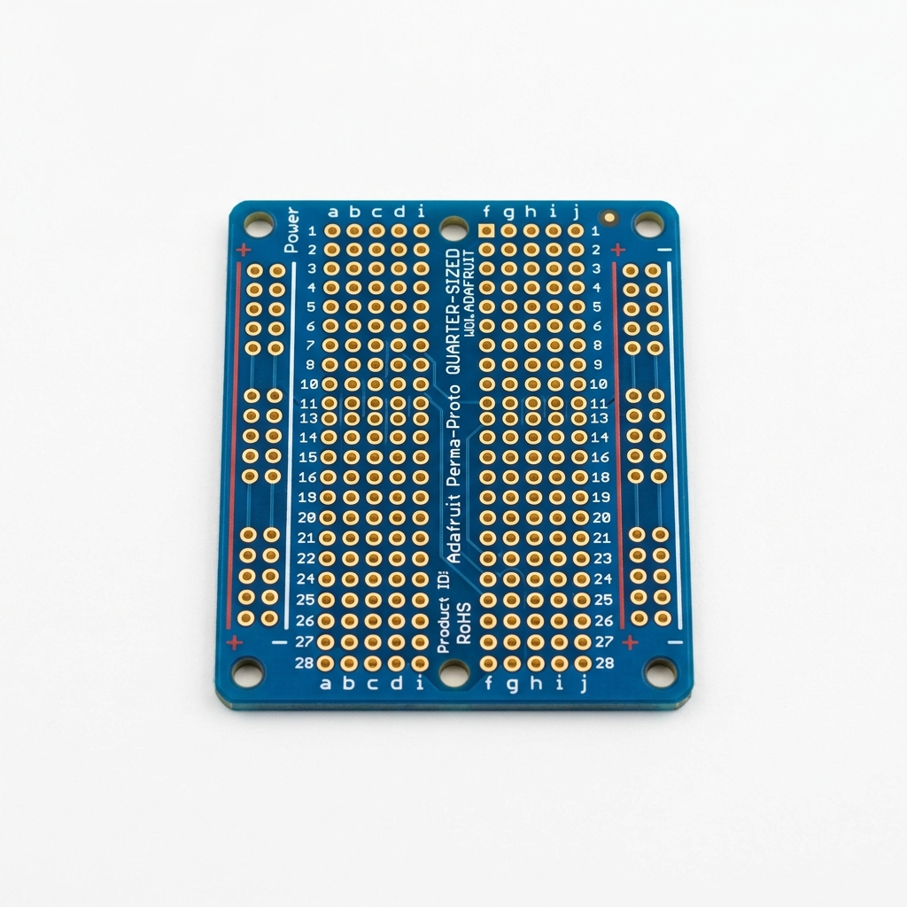
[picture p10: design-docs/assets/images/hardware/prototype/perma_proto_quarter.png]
| Illumination/Carrier | LED Solder Board (1) | Mounting wavelength LEDs | Adafruit Perma-Proto Quarter | $5.95 | [Adafruit](https://www.adafruit.com/product/589) |  | **High**: Version 1 LED carrier board. Solder LEDs here, wire to TLC5947. Replace with custom circular PCB later. |
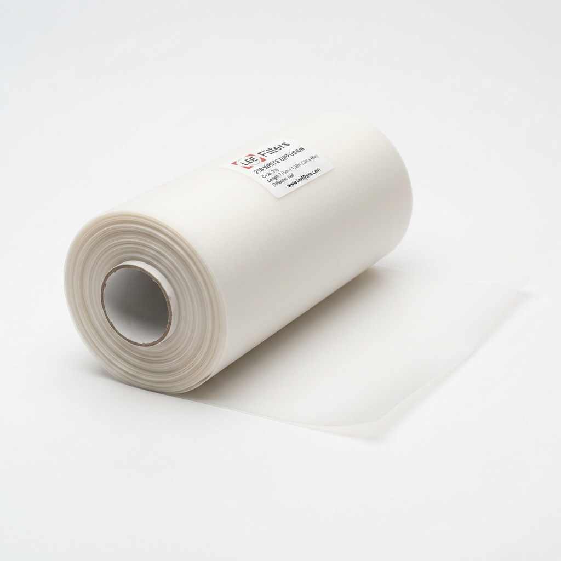
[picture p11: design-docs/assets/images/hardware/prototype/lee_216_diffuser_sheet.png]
| Illumination/Optics | Diffuser Sheet (1) | Smooths LED illumination | LEE Filters 216 White Diffusion | $10.00 | [Amazon Search](https://www.amazon.com/s?k=Lee+216+White+Diffusion+Filter+Sheet) |  | **Critical**: Cut squares/circles and mount between LED carrier and sample to reduce hotspots. |
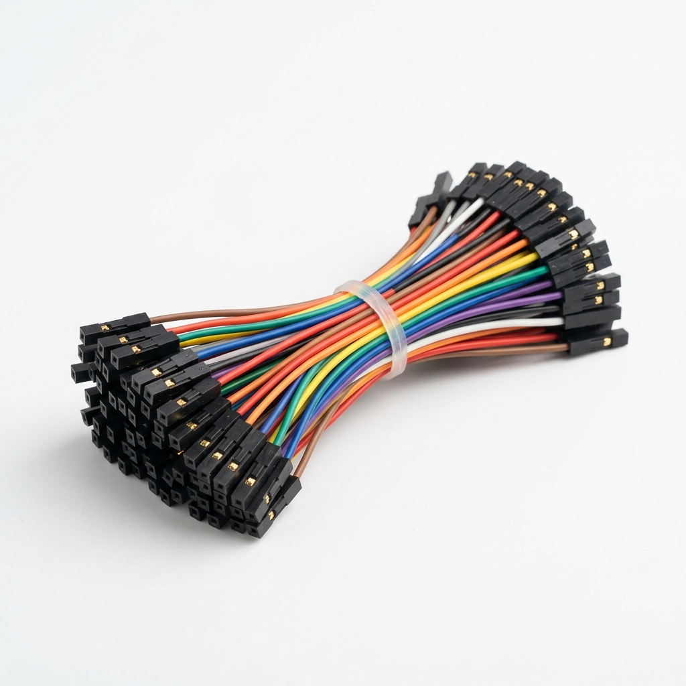
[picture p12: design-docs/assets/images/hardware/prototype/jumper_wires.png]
| Illumination/Wiring | Jumper Wire Kit (1) | Wiring Pico, TLC5947, Carrier | Premium Female/Female Jumper Wires | $3.95 | [Adafruit](https://www.adafruit.com/product/266) |  | **Medium**: Use short wires to reduce clutter. |
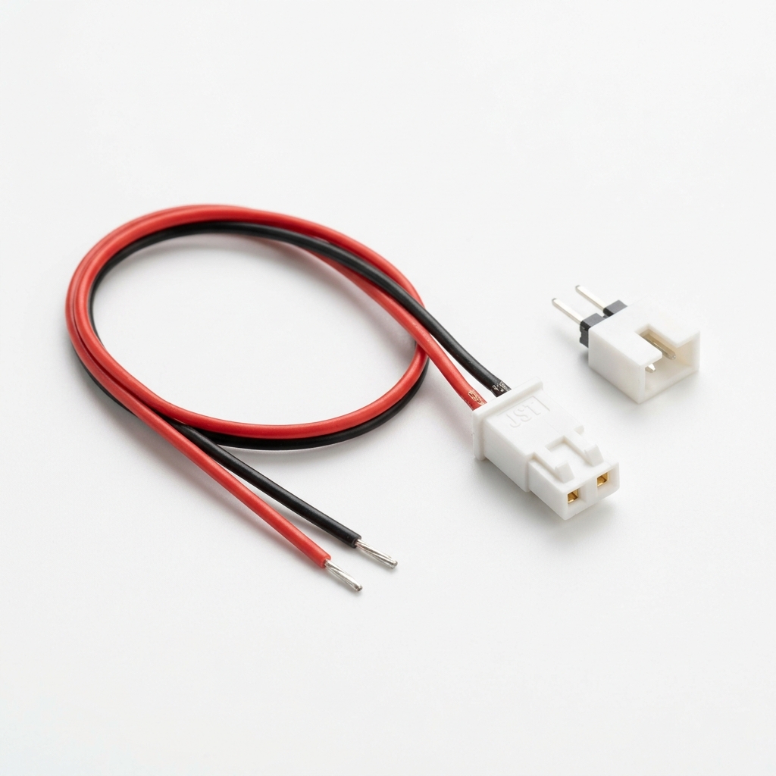
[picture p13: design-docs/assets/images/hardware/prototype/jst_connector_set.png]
| Illumination/Wiring | JST Connector Kit (1) | Removable carrier wiring | JST PH 2-pin Cable Set | $4.95 | [Adafruit](https://www.adafruit.com/product/3814) |  | **Medium**: Makes LED carrier board replaceable. |
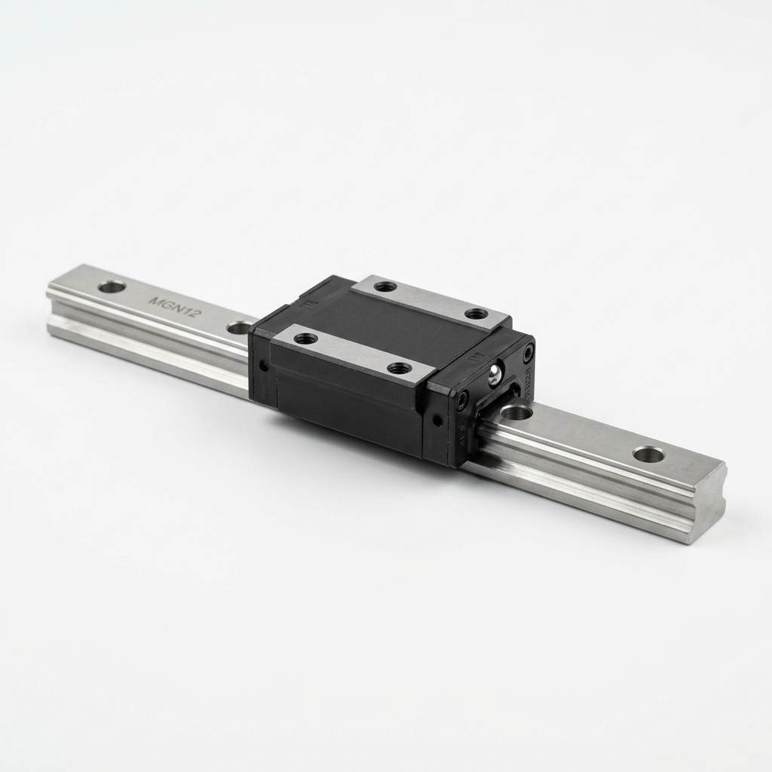
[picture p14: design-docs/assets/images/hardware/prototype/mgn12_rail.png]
| Motion | Linear Rails (2) | XY smooth travel | Generic MGN12 (KB3D) | $20.00 | [KB3D](https://kb-3d.com/store/linear-rails-carriages/1000-hiwin-mgn12h-linear-rail-carriage-1647468641973.html) |  | **High**: Avoid printed sliding parts. |
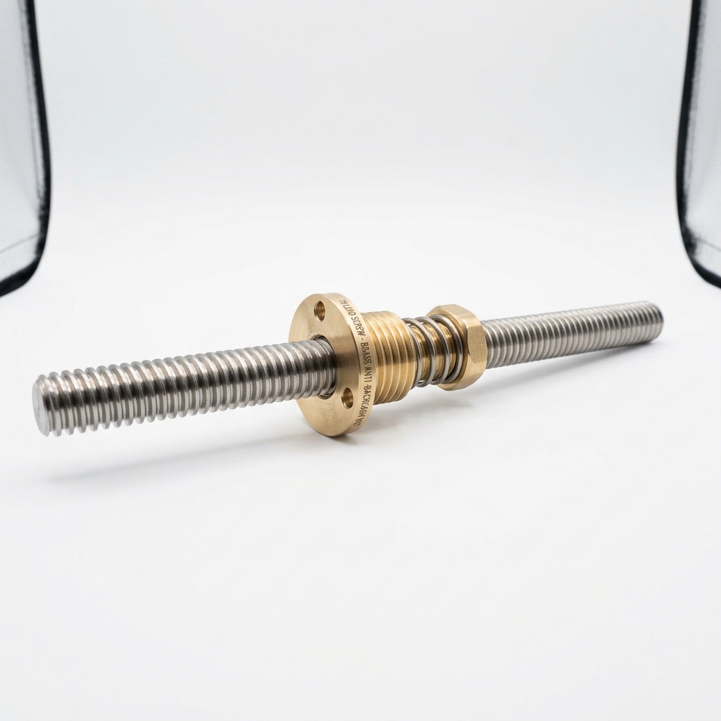
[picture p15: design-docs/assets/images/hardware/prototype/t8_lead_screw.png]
| Motion | Lead Screw (2) | XY actuation | Standard threaded rod | $15.00 | [Amazon Search](https://www.amazon.com/s?k=T8+Lead+Screw+400mm) |  | **High** |
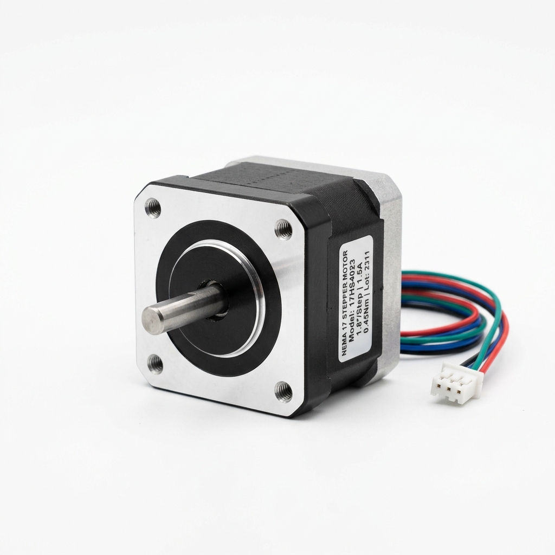
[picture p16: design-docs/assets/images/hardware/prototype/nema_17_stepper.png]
| Motion | Stepper Motor (2) | Automated XY | 28BYJ-48 (Not rec) | $14.00 | [Pololu](https://www.pololu.com/product/2267) |  | **Low**: Start with manual knobs. |
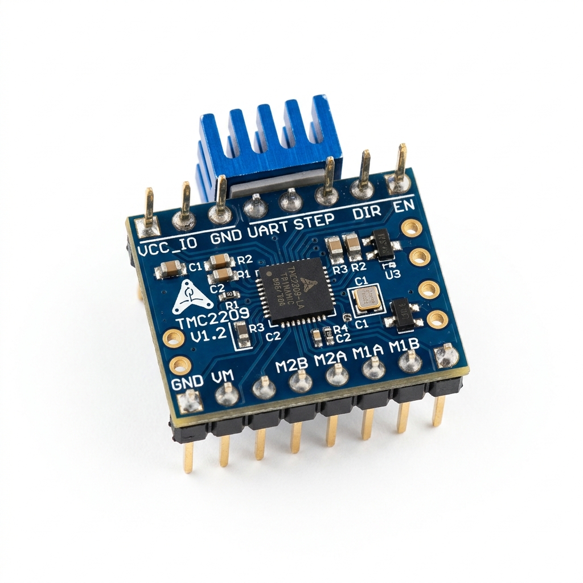
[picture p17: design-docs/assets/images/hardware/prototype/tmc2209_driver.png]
| Motion | Motor Driver (2) | Control Stepper | A4988 | $8.00 | [Pololu](https://www.pololu.com/product/3281) |  | **Low**: TMC provides silent operation. |
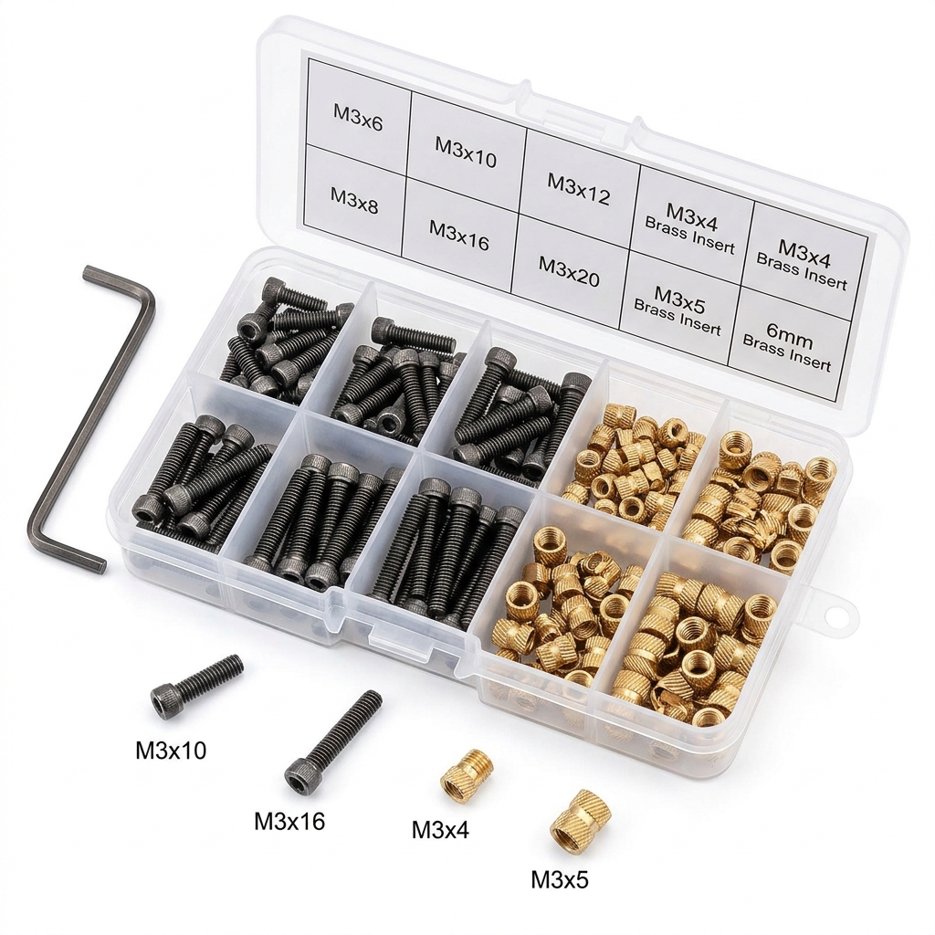
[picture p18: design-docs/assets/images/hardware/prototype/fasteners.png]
| Fasteners | Screw Kit (1) | Assembly | Generic Kit | $15.00 | [Amazon Search](https://www.amazon.com/s?k=M3+Metric+Machine+Screw+Assortment+Kit) |  | **High** |
| Fasteners | Threaded Inserts (1) | Assembly | Generic M3 inserts | $12.00 | [Amazon Search](https://www.amazon.com/s?k=M3+Heat+Set+Threaded+Inserts) |  | **High**: Required for durable threads. |

## Version 1 Multispectral LED Diode Set

| Channel | Wavelength | Qty | Candidate Product | Verified Price | Vendor Link | Image | Notes |
| :--- | :--- | :--- | :--- | :--- | :--- | :--- | :--- |
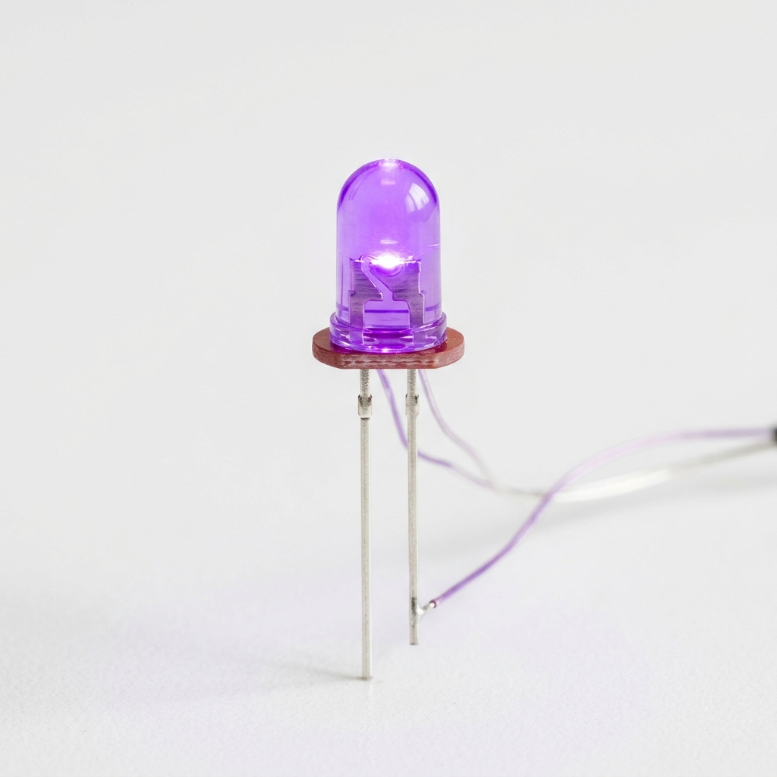
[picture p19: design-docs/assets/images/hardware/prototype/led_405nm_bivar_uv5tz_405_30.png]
| Violet / Soret | 405 nm | 3-5 | Bivar UV5TZ-405-30 5mm | $1.00 ea | [DigiKey](https://www.digikey.com/en/products/detail/bivar-inc/UV5TZ-405-30/4991471) |  | Hemoglobin/Soret-region contrast. Use eye safety precautions. |
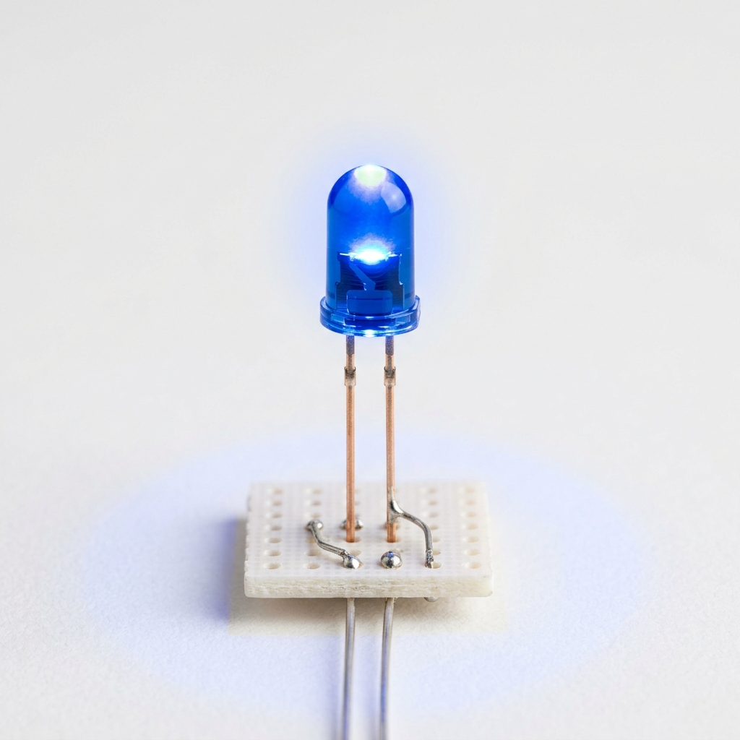
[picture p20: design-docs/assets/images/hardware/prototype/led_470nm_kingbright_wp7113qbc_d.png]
| Blue | 470 nm | 3-5 | Kingbright WP7113QBC/D 5mm | $0.50 ea | [DigiKey](https://www.digikey.com/en/products/detail/kingbright/WP7113QBC-D/3084651) |  | Blue channel for stain and WBC contrast. |
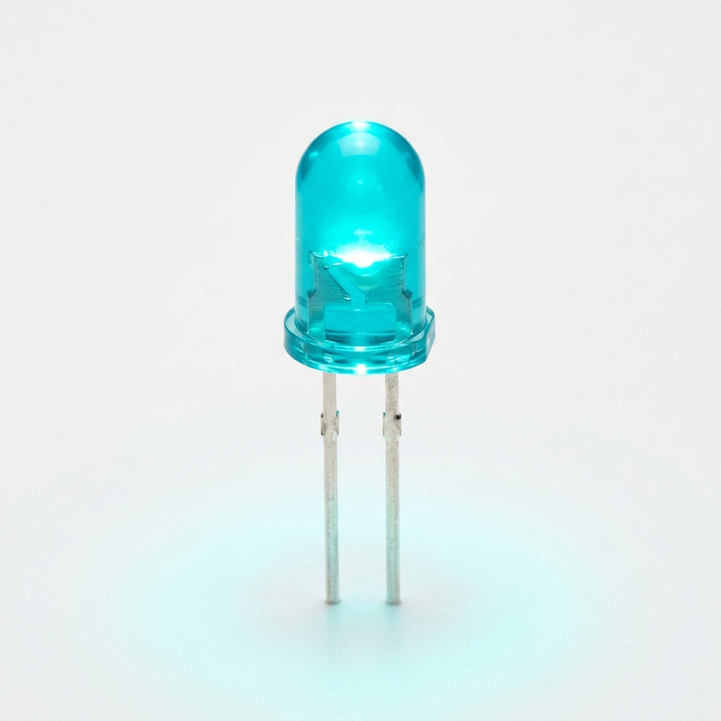
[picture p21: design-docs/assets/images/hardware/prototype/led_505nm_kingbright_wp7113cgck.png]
| Cyan | 505 nm | 3-5 | Kingbright WP7113CGCK 5mm | $0.50 ea | [DigiKey](https://www.digikey.com/en/products/detail/kingbright/WP7113CGCK/3084605) |  | Optional extra channel between blue and green. |
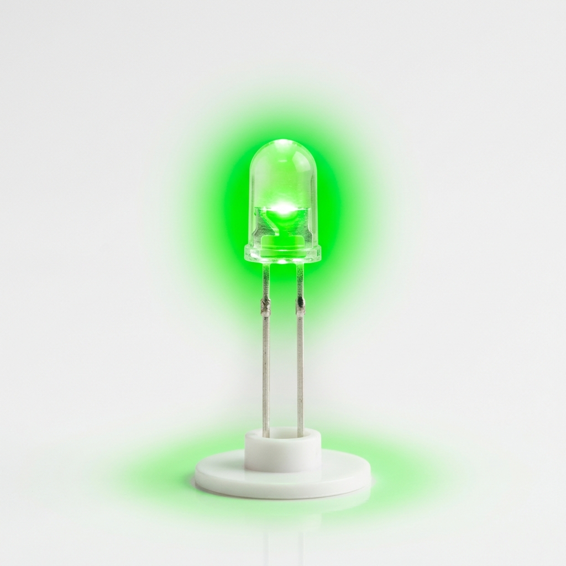
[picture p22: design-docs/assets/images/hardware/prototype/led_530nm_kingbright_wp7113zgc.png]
| Green | 530 nm | 3-5 | Kingbright WP7113ZGC 5mm | $0.50 ea | [DigiKey](https://www.digikey.com/en/products/detail/kingbright/WP7113ZGC/3084705) |  | Core morphology/RBC contrast channel. |
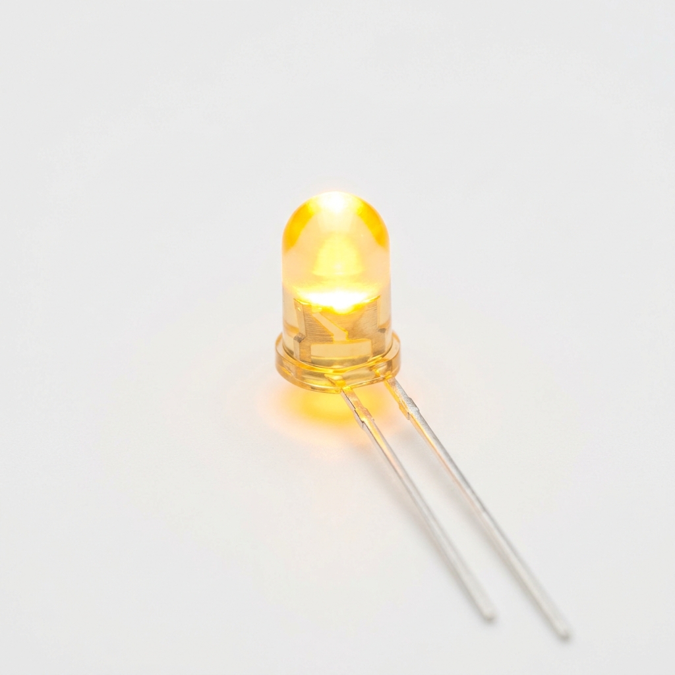
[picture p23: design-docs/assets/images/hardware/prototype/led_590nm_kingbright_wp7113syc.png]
| Yellow | 590 nm | 3-5 | Kingbright WP7113SYC 5mm | $0.50 ea | [DigiKey](https://www.digikey.com/en/products/detail/kingbright/WP7113SYC/3084687) |  | Hemoglobin-related contrast channel. |
| Red | 625 nm | 3-5 | Kingbright WP7113ID 5mm | $0.35 ea | [DigiKey](https://www.digikey.com/en/products/detail/kingbright/WP7113ID/3084643) |  | Lower absorption morphology and normalization channel. |
| Deep Red | 660 nm | 3-5 | Marktech MTE6600N2 660nm | $1.50 ea | [DigiKey](https://www.digikey.com/en/products/detail/marktech-optoelectronics/MTE6600N2/6006450) |  | Deep red comparison/normalization channel. |
| NIR (Optional) | 850 nm | 3-5 | Vishay TSHG6400 850nm | $1.00 ea | [DigiKey](https://www.digikey.com/en/products/detail/vishay-semiconductor-opto-division/TSHG6400/1681283) |  | Optional NIR channel. Verify camera sensitivity. |

> [!NOTE]
> **Recommended Version 1 Wiring:**
> Raspberry Pi -> USB serial -> Raspberry Pi Pico -> SPI-style pins -> Adafruit TLC5947 -> individual LED channels on solderable LED carrier board. Turn on one wavelength group at a time, capture an image, turn it off, then switch to the next wavelength.

> [!WARNING]
> The TLC5947 design is for low-power LEDs only. If illumination is too dim after the diffuser and microscope optics, upgrade to 1W narrowband LEDs mounted on aluminum star boards with dedicated constant-current drivers such as Mean Well LDD-350H or LDD-500H.

## Estimated Total Prototype Cost
- **Absolute cheapest build (Manual XY, 10X lens):** ~$150
- **Recommended prototype build (MGN12 rails, 40X Plan lens, manual):** ~$230
- **Automated motion build (add NEMA 17 & drivers):** ~$280
- **Multispectral low-power LED prototype add-on:** ~$50 to $100 depending on LED quantities, diffuser, connectors, and shipping.
- **High-power multispectral LED upgrade:** Future version, not included in current prototype BOM.

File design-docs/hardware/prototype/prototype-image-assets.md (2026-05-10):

# Prototype Image Assets

This document manages the visual assets, diagrams, and CAD renders used in the prototype documentation.

## Image Management Rules

1. **Vendor Images**: It is acceptable to download and commit product images found via web search to ensure the documentation remains complete even if external links die. 
2. **Local Storage**: Always download images and place them in the appropriate `assets/` directory rather than hotlinking them.
3. **Prefer self-created diagrams**: Use Mermaid.js within Markdown for system diagrams, flowcharts, and architecture maps. These render natively on GitHub.
4. **CAD Screenshots**: Screenshots of your own CAD models are encouraged. Use `.png` format.
5. **Image Inventory**: Every image saved in the repository must be tracked in the `design-docs/sources/image-sources.csv` file.

## Image Folder Structure
- `design-docs/assets/images/hardware/prototype/`: Photos of the actual built prototype.
- `design-docs/assets/images/hardware/production/`: Photos or renders of production hardware.
- `design-docs/assets/diagrams/`: Non-Mermaid diagrams (e.g., complex SVG optical ray traces).
- `design-docs/assets/stl-previews/`: Renders or screenshots of individual STL parts.

## File Naming Conventions
- Use lowercase, hyphen-separated names: `assembled-prototype-v1.png`.
- Provide descriptive names, not generic ones like `image1.jpg`.

## Alt Text Conventions
Always include descriptive alt text for accessibility and context if the image fails to load.
*Example:* `![CAD render of the 3D printed optical tower showing the IMX296 camera mount](.../optical-tower.png)`

## Visual Placeholders

If an image is needed but not yet created, use an HTML comment placeholder in the markdown files:

<!-- TODO: Add product image: Raspberry Pi 5 board. Source: [URL] -->
<!-- TODO: Add CAD render: prototype frame v1 -->
<!-- TODO: Add optical path diagram -->

## Adding Vendor Image References
When referencing a specific part in documentation without committing an image, use markdown links to point the reader to the source:
`[View Raspberry Pi 4 on official site](https://www.raspberrypi.com/products/raspberry-pi-4-model-b/)`

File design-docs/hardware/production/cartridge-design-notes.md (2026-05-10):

# Cartridge Design Notes

*Note: These notes focus purely on the engineering constraints of the imaging target. No biological sample handling procedures are provided.*

The transition from a prototype using standard glass slides to a production system requires a specialized cartridge. This is the single most critical component for ensuring reliable quantitative data.

## Key Engineering Requirements

- **Known Volume**: The imaging chamber must hold a precisely defined volume of fluid.
- **Known Depth**: The height of the imaging chamber (z-axis) must be tightly controlled across its entire area. If the depth varies, the calculated volume per field-of-view varies, ruining concentration accuracy.
- **Fixed Imaging Window**: The cartridge must define a specific area intended for the scanning process, ensuring the AI only processes the valid region.
- **Alignment Keying**: The cartridge must feature physical keying or registration marks (asymmetric design) to ensure it seats identically in the scanner every time, preventing user error.
- **Optical Clarity**: The materials used for the top and bottom of the imaging chamber must be optically clear, with minimal autofluorescence or distortion in the target wavelengths (400nm - 700nm).
- **Manufacturing Tolerance**: The dimensional tolerances of the imaging chamber directly impact the count-to-concentration calculation. These tolerances must be rigorously defined and validated during molding.
- **Anti-Bubble Geometry Consideration**: The fluidic path must be designed to minimize the introduction or trapping of air bubbles in the imaging region. Bubbles cause massive optical distortion, ruining both CV and AI segmentation.

## Enabling Concentration Calculations

The primary purpose of the known-volume cartridge is to enable the transition from a raw "object count" to an absolute "concentration."

By knowing:
1. The **Area Imaged** (Field of View X * Field of View Y * Number of stitched frames).
2. The **Depth** of the cartridge chamber.
3. Any **Dilution Factors** introduced prior to imaging.

The system can convert the count derived from the AI/CV pipeline into a standard concentration metric (e.g., cells per microliter).

*Formula:*
`Volume Imaged = Area Imaged * Chamber Depth`
`Concentration = (Total Count / Volume Imaged) * Dilution Factor`

## Calibration Relationship
The system software must maintain a calibration profile that maps the camera's pixel dimensions to physical microns to accurately calculate the *Area Imaged*.

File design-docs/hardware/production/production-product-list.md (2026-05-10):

# Production Product List

This table outlines the anticipated shift in components from the prototype phase to the production phase.

| Subsystem | Prototype Option | Production Option | Why Upgrade | Supplier Type | Estimated Cost | Risk | Notes |
| :--- | :--- | :--- | :--- | :--- | :--- | :--- | :--- |
| **Main Frame** | 3D Printed PETG | Folded Sheet Metal / Machined Al | Rigidity, thermal stability, repeatability | Custom Fabrication | $50 - $150 | Tooling costs | |
| **Enclosure** | Cardboard/None | Injection Molded Plastic or Sheet Metal | Light blocking, dust protection, aesthetics | Custom Fabrication | $30 - $100 | High upfront tooling cost for molding | |
| **Linear Motion (XY)** | 8mm smooth rods or cheap generic MGN12 | High-grade linear guides (e.g., genuine HIWIN/THK) | Precision, reduced backlash, long lifespan | Automation Supplier | $100 - $300 | Sourcing authentic parts, cost | |
| **Actuation (Motors)** | NEMA 17 Open Loop | NEMA 17 Steppers with Encoders (Closed Loop) | Prevent missed steps, guarantee positioning | Automation Supplier | $50 - $120 | Complexity in tuning closed-loop drivers | |
| **Optics Mount** | 3D Printed Plastic | Machined Aluminum Block | Prevent thermal expansion from shifting focus | Custom Fabrication | $30 - $80 | Machining tolerances | |
| **Illumination** | Generic White LED Ring | Custom PCB with specific wavelength LEDs | Consistency across devices, exact spectral control | PCB Manufacturer | $20 - $50 | Sourcing specific narrow-band LEDs | Requires custom driver circuit |
| **Sample Holder** | 3D Printed Slide Clamp | Injection Molded Cartridge Receiver | Needed for known-volume concentration calc | Medical Plastics | $5 - $15 | High tooling cost, fluidic issues | |
| **Compute** | Raspberry Pi 4 | Raspberry Pi Compute Module 4/5 (CM4/CM5) | Allows custom carrier board, smaller footprint | Electronics Distributor| $40 - $70 | Supply chain availability of CM modules | Requires custom carrier PCB |

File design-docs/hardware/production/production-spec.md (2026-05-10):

# Production Hardware Specification

The production hardware represents the evolution of the system from a rapidly iteratable prototype into a reliable, repeatable, and manufacturable device suitable for field use and data collection at scale.

## Production Design Goals
- **Manufacturability**: Design for Assembly (DFA) using standard fasteners, minimal manual adjustment, and easily sourced core components.
- **Reliability**: Withstand shipping and daily field use without losing optical alignment.
- **Serviceability**: Allow easy field replacement of the camera module, LED array, or main compute board without requiring full optical recalibration.

## Core Advancements from Prototype

- **Cartridge Interface**: The system will move away from standard glass slides and manual clamping to a custom, engineered cartridge slot.
- **Known-Volume Imaging**: The core goal of the production hardware is to enable absolute concentration calculations. This requires the hardware to image a tightly controlled, specific volume of fluid.
- **Optical Stability**: Transition from 3D printed towers to sheet metal, machined aluminum, or rigid injection-molded chassis components to ensure the focal plane remains perfectly perpendicular to the sensor.
- **Controlled Illumination**: Replace generic white LEDs with a custom-designed PCB containing calibrated multispectral LEDs (e.g., 405nm, 470nm, 530nm, 660nm) with current-controlled feedback to ensure intensity does not drift over time.
- **Controlled Motion**: Use precision linear guides (e.g., HIWIN/THK) and closed-loop steppers (steppers with encoders) to prevent missed steps, stage backlash, and ensure perfect overlap for stitching.
- **Calibration Workflow**: Integrate a hardware calibration routine, potentially using a fixed optical target within the device or a special calibration cartridge inserted periodically.

## Production Materials
- **Parts that should be machined/folded metal**: Main chassis, Z-axis optical tower, objective lens mount.
- **Parts that should be injection molded**: Exterior enclosure, cartridge receiver.
- **Parts that can remain 3D printed or low-cost**: Internal cable routing clips, non-load-bearing baffles for light blocking.

## Failure Modes & Mitigations
- **Failure**: LED intensity degrades over thousands of scans, changing image brightness and breaking AI models.
    - **Mitigation**: Implement a photodiode feedback loop on the LED board to automatically adjust PWM/current to maintain constant lux.
- **Failure**: Dust accumulating on the sensor over time.
    - **Mitigation**: Sealed optical path from the objective lens to the camera sensor.
- **Failure**: User inserts cartridge incorrectly.
    - **Mitigation**: Asymmetric cartridge design (poka-yoke) so it only fits one way.

## Validation Plan
1. **Vibration testing**: Verify optical alignment holds after simulated transit.
2. **Thermal testing**: Verify image quality does not degrade as the internal enclosure temperature rises from Pi/LED heat.
3. **Repeatability testing**: Scan the same calibration target 100 times, dismounting and remounting the target each time, to verify XY positioning and focus repeatability.

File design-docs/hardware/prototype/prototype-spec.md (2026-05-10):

# Prototype Hardware Specification

## 1. Purpose
The prototype hardware provides a rapidly iterable platform for capturing multispectral microscope images, testing stitching algorithms, and developing the initial Computer Vision (CV) and AI pipeline.

## 2. Prototype Success Criteria
- Capture clear microscope images capable of resolving individual cells.
- Capture 5 to 10 overlapping fields of view (FOV).
- Successfully stitch these FOVs with no visible tearing or misalignment.
- Maintain focus across the stitching grid without adjusting the Z-axis (testing XY planarity).

## 3. Functional Requirements
- Securely hold a standard 25x75mm microscope slide.
- Illuminate the sample with controlled intensity.
- Focus the image onto the camera sensor.
- Move the slide in X and Y directions with sufficient precision to achieve 40% to 60% overlap between adjacent images.

## 4. Non-Functional Requirements
- **Cost**: Keep the BOM under $250.
- **Assembly Time**: Under 4 hours for an experienced engineer.
- **Accessibility**: Use widely available parts and standard 3D printing techniques.

## 5. Subsystem Requirements
- **Compute**: Raspberry Pi 4 (4GB minimum) or Pi 5.
- **Camera**: InnovaMaker IMX296 global shutter sensor to eliminate rolling shutter distortion during capture.
- **Optics**: 10X or 40X Plan Achromatic objective. "Plan" is critical to ensure a flat field of view for reliable edge-to-edge stitching.
- **Illumination**: Dimmable LED source, initially white, upgradable to specific wavelengths (e.g., 405nm, 470nm, 530nm, 660nm).

## 6. Mechanical Architecture
A modular, mostly 3D-printed chassis. The frame must be rigid enough to prevent the objective lens from vibrating relative to the sample.

## 7. Optical Architecture
```mermaid
flowchart TD
    LED[LED Ring] --> Diffuser[Diffuser Panel]
    Diffuser --> Sample[Microscope Slide]
    Sample --> Objective[40X Plan Achromatic Objective]
    Objective --> Sensor[IMX296 Sensor]
```
*Note: Depending on the objective design, a tube lens may be required if using an infinity-corrected objective. For standard 160mm objectives, precise spacing to the sensor is required.*

## 8. Illumination Architecture
Bottom-up transmitted light configuration. A diffuser is mandatory to prevent imaging the individual LED dies.

## 9. Motion Architecture
```mermaid
flowchart LR
    Knob[Manual Knob / Stepper] --> LeadScrew[T8 Lead Screw]
    LeadScrew --> AntiBacklash[Anti-Backlash Nut]
    AntiBacklash --> Carriage[XY Carriage]
    Carriage --> Rails[MGN12 Rails / Smooth Rods]
```

### XY Stage Comparison

| Option | Cost | Difficulty | Accuracy | Recommendation |
| :--- | :--- | :--- | :--- | :--- |
| 1. Fully printed XY stage | ~$2 | Low | Very Low (Stiction, backlash) | Avoid for precise stitching |
| 2. Printed stage + 8mm smooth rods | ~$15 | Medium | Low-Medium | Acceptable for absolute budget |
| 3. MGN12 Linear Rail Stage | ~$40 | Medium | High | **Recommended** |
| 4. Cheap manual microscope stage | ~$30 | Low | Medium (Hard to automate) | Good for manual testing only |

*Recommendation:* Printed frame + MGN12 rails + T8 lead screw + manual knob first, adding NEMA 17 steppers later.

## 10. Electronics Mounting
Provide isolated mounting points for the Raspberry Pi to prevent its cooling fan (if used) from inducing vibration into the optical path.

## 11. 3D Printed Components
- The frame, brackets, camera mount, slide holder, LED/diffuser mount, Pi mount, and motor brackets can be printed.
- **Do not 3D print:** optical lenses, lead screws, precision rails, or bearings.

## 12. Purchased Components
Off-the-shelf fasteners (M3), rails, objectives, and electronics. See the product list.

## 13. Recommended Prototype Dimensions and Assumptions
- Max footprint: 200mm x 200mm.
- Max height: 300mm.
- Assumes standard 160mm optical tube length if using standard biological objectives.

## 14. Tolerances
- XY Planarity: The stage must slide without tilting more than the depth of field of the objective (typically < 2 microns for 40X) to maintain focus across a scan.
- 40% to 60% overlap is required to give the stitching algorithm sufficient feature tolerance.

## 15. Failure Modes
- **Vibration**: Blurs the image. (Use stiff infill, isolating feet).
- **Z-Drift**: Gravity pulling the focus down over time. (Use a fine-pitch lead screw).

## 16. Open Questions
- Should we prioritize an infinity-corrected optical path early on, which allows easy insertion of beam splitters or filters later, or stick to the cheaper 160mm fixed tube length for the prototype?

## 17. Next Iteration Plan
Transition from manual knobs to automated stepper motor control (NEMA 17 with TMC2209 drivers) for fully automated scanning.

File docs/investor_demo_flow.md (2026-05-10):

# Investor Demo Flow

1. Power on Pi and wait 1 minute.
2. Ensure you are on the same WiFi network.
3. Navigate to `http://raspberrypi.local:8000`
4. Explain the "Multispectral CBC Imaging" architecture.
5. Emphasize that this is a research prototype.
6. Click "Run Multispectral Demo Scan".
7. Show how the 5 simulated wavelengths are "captured" and appear in the gallery.
8. Explain the future AI pipeline.

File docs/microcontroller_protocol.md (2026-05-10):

# Microcontroller Protocol

Serial 115200 baud, 8N1.

**Commands**
- `HOME`: Homes XYZ
- `MOVE X=<um> Y=<um>`: Moves stage
- `FOCUS Z=<um>`: Moves focus
- `LED CH=<channel>`: Sets LED channel
- `TRIGGER ID=<capture_id>`: Triggers capture
- `STATUS`: Gets status
- `ESTOP`: Emergency stop

**Responses**
- `OK`
- `DONE ID=<capture_id>`
- `ERR <message>`

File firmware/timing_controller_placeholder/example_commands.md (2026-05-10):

# Example Commands

```text
> HOME
< OK
> MOVE X=100 Y=200
< DONE
> LED CH=2
< OK
> TRIGGER ID=5
< DONE ID=5
```

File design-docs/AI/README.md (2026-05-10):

# AI and Computer Vision

This directory contains the design documentation for the Artificial Intelligence and classical Computer Vision (CV) pipelines used to process images captured by the CBC scanner.

The goal is to transform raw microscope images into robust object counts and classifications.

## Workflow Overview

1. **Model Strategy (`01-model-strategy.md`)**: Deciding the core architectures (e.g., YOLO vs. U-Net) and whether to train from scratch or fine-tune.
2. **Pretraining Plan (`02-pretraining-plan.md`)**: Leveraging open-source datasets (like BCCD or BloodMNIST) to build foundational model weights before using our own device data.
3. **Computer Vision System (`03-computer-vision-system.md`)**: Using classical algorithms (thresholding, watershed) for immediate object detection, quality control, and generating pseudo-labels for the AI.
4. **Final AI/CV Pipeline (`04-final-ai-cv-pipeline.md`)**: The integrated production flow that merges hardware acquisition, CV, and AI models into a single continuous loop.
5. **AI Tech Stack (`05-ai-tech-stack.md`)**: The specific Python libraries (PyTorch, Ultralytics), environment managers (uv), and best practices used for development.
6. **Dataset Format and Labeling (`06-dataset-format-and-labeling.md`)**: How data is structured, annotated, and prepared for training.
7. **Evaluation Metrics (`07-evaluation-metrics.md`)**: The statistical methods used to prove the models are actually working (e.g., mAP, Dice score, Count Error).

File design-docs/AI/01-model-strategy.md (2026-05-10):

# Model Strategy

**Question**: Should we train from scratch or use a pretrained model?

**Recommendation**: Start from pretrained models. Do not train from scratch initially. Use our compute budget for domain adaptation, public dataset pretraining/fine-tuning, self-supervised learning, and internal device fine-tuning.

Training from scratch requires massive datasets and extensive tuning. Leveraging existing foundation models accelerates development and improves generalization.

## Model Families and Specific Options

### Detection and Segmentation
- **Ultralytics YOLOv8-seg or YOLO11-seg**: Highly recommended for fast, real-time instance segmentation and detection. Excellent ecosystem and easy export to edge devices (like the Raspberry Pi or an attached Coral TPU).
- **Ultralytics YOLOv8/YOLO11 (Detection only)**: A solid baseline if bounding boxes are sufficient and full masks are too computationally expensive.
- **RT-DETR**: A strong transformer-based alternative to YOLO for the detection baseline.
- **Mask R-CNN (via Detectron2 or TorchVision)**: The classical standard for instance segmentation. Heavier than YOLO, but highly accurate.
- **U-Net / UNet++ (via `segmentation_models_pytorch`)**: The standard for semantic segmentation in biomedical imaging. Great for delineating complex cell boundaries.
- **Cellpose / StarDist**: Specialized models pre-trained specifically on cellular structures. Excellent for out-of-the-box cell segmentation, though they may require tuning for blood cells specifically.
- **Segment Anything (SAM 2)**: Useful for *assisted labeling* (human-in-the-loop annotation). It should not be used for unsupervised, automated counting in production unless rigorously validated, due to hallucination risks and high compute costs.

### Classification (WBC Subtyping)
- **ResNet50**: The reliable, standard baseline.
- **EfficientNet-B0/B3**: Better accuracy-to-parameter ratio, excellent for edge deployment.
- **ConvNeXt-Tiny**: Modern CNN architecture that competes with Vision Transformers.
- **ViT-B/16**: Vision Transformer, requires more data to train effectively but offers high performance.
- **DINOv2**: Excellent for extracting embeddings for self-supervised learning.
- **BioMedCLIP**: Experimental feature extractor for zero-shot or few-shot tasks.

### Image Quality Model
- **Classical**: Sharpness metrics such as Laplacian variance (requires no training).
- **Deep Learning**: A small CNN classifier (or a lightweight EfficientNet/ResNet) trained as a binary classifier to flag images as "usable" or "unusable" (e.g., severe blur, totally empty, huge bubble).

### Counting Strategy
- **Primary Method**: Count directly from the resulting masks or bounding boxes produced by the detection/segmentation models.
- **Future Research Option**: Direct density-map counting models (e.g., CSRNet style) if cell density becomes too high for instance segmentation to handle clumps.
- **Validation**: Constantly compare the classical CV count vs. the AI count vs. human-reviewed labels to track drift.

## Defined Tasks

1. **Image quality detection**: Reject bad frames immediately.
2. **Object detection**: Draw bounding boxes around cells.
3. **Instance segmentation**: Draw precise pixel masks for individual overlapping cells.
4. **Semantic segmentation**: Classify every pixel in the image (e.g., background, RBC, WBC).
5. **WBC classification**: Categorize segmented WBCs into subtypes (Neutrophil, Lymphocyte, etc.).
6. **Pseudo-labeling**: Use classical CV to auto-generate training data.
7. **Active learning**: Automatically flag edge cases for human review.
8. **Uncertainty estimation**: Ensure the model provides a confidence score for its counts.
9. **Count error tracking**: Monitor performance against clinical baselines.

## Decision Table

| Task | Recommended First Model | Alternative | Reason |
| :--- | :--- | :--- | :--- |
| **Detection / Instance Seg** | YOLO11-seg | Mask R-CNN | YOLO is significantly faster and easier to deploy on edge hardware while maintaining high accuracy. |
| **Semantic Seg** | UNet (EfficientNet backbone) | DeepLabV3+ | UNet is the proven standard for biomedical tasks. `segmentation_models_pytorch` makes it trivial to swap backbones. |
| **Classification** | EfficientNet-B0 | ResNet50 | EfficientNet offers a better trade-off between speed and accuracy for classifying cropped cell images. |
| **Quality Control** | Variance of Laplacian (CV) | Small CNN | Classical CV is instant and requires zero labeled data. Neural networks can be added later for complex artifact detection. |

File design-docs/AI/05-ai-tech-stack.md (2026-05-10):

# AI Tech Stack & Best Practices

This document defines the software stack, project structure, and engineering best practices for developing the AI models.

## Recommended Stack

- **Language**: Python 3.11 or 3.12
- **Environment & Dependencies**: `uv` (significantly faster and more reliable than pip/conda).
- **Deep Learning Framework**: `PyTorch` and `torchvision`.
- **Model Libraries**: 
  - `ultralytics` (for YOLOv8/YOLO11).
  - `segmentation-models-pytorch` (for U-Net, DeepLab, etc.).
  - *Optional*: `Detectron2` (if Mask R-CNN is pursued).
- **Computer Vision**: `OpenCV` (`cv2`), `scikit-image` (`skimage`).
- **Data Science**: `NumPy`, `SciPy`, `pandas`, `matplotlib`.
- **Augmentation**: `albumentations` (crucial for medical imaging augmentations like elastic transform, grid distortion, and color jitter).
- **Utilities**: `tqdm` (progress bars), `pydantic` (data validation).
- **Configuration**: `hydra` or `OmegaConf` (for config-driven experiments).
- **Experiment Tracking**: `MLflow` or `Weights & Biases (W&B)` (for tracking loss, metrics, and hyperparameters).
- **Annotation & Review**: `FiftyOne`, `CVAT`, `Label Studio`, or `Roboflow`.
- **Data Versioning**: `DVC` (Data Version Control) or `Git LFS`.
- **Code Quality**: `pytest` (testing), `ruff` (linting/formatting), `mypy` (optional type checking), `pre-commit` hooks.

## Environment Setup (Using `uv`)

```bash
uv init
uv add torch torchvision opencv-python scikit-image pandas numpy scipy albumentations ultralytics segmentation-models-pytorch matplotlib tqdm pydantic
uv run python scripts/train_detector.py
```

## Suggested Project Structure

```
ai/
  pyproject.toml
  uv.lock
  src/
    cbc_ai/
      data/         # Dataset loaders, transforms
      cv/           # Classical CV pipelines
      models/       # PyTorch model definitions/wrappers
      training/     # Training loops, loss functions
      evaluation/   # Metrics calculation
      inference/    # Deployment and prediction scripts
      utils/        # Logging, config parsing
  configs/          # YAML configuration files
  notebooks/        # Jupyter notebooks for EDA and visualization
  scripts/          # Entry points (e.g., train.py, evaluate.py)
  tests/            # Pytest test suite
```

## Engineering Best Practices

- **Config-driven experiments**: Never hardcode hyperparameters. Use YAML configs.
- **Fixed random seeds**: Always seed PyTorch, NumPy, and Python's `random` module at the start of training to ensure reproducibility.
- **Version datasets**: Treat data like code. Use DVC to track dataset versions alongside model weights.
- **Locked test set**: Establish a representative test set immediately and *never* train on it. 
- **Save preprocessing config with the model**: The exact normalization values (mean/std) and resizing logic used during training must be saved alongside the `.pt` or `.onnx` model file to ensure inference matches training.
- **Log metrics every run**: Use MLflow/W&B to track every experiment.
- **Separate Pseudo-labels**: Keep a strict metadata separation between human-verified labels and AI/CV generated pseudo-labels. Train models primarily on human-verified data; use pseudo-labels only for pretraining or with weighted loss.
- **Model Cards**: Create a model card for every deployed model detailing its training data, performance metrics, and known limitations.

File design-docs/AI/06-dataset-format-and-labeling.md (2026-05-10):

# Dataset Format and Labeling Strategy

This document outlines how data is categorized, annotated, and formatted.

## Labeling Strategy

### 1. Label Sources
- **Human Labels**: Ground truth annotations created or verified by a human expert. Highest priority during training.
- **CV Pseudo-labels**: Generated purely by classical computer vision algorithms. Used to bootstrap early models.
- **AI Pseudo-labels**: Generated by a highly confident trained model. 
- **Active Learning**: The model flags low-confidence predictions, which are queued for a human to review. Once reviewed, they become Human Labels.

### 2. Review Workflow & Confidence Thresholding
Predictions from the AI or CV pipeline are scored.
- `Confidence > 0.95`: Automatically accepted as an AI Pseudo-label.
- `0.40 < Confidence < 0.95`: Sent to the Human Review Queue (e.g., in Label Studio).
- `Confidence < 0.40`: Discarded.

### 3. Object Classes
The dataset must account for more than just cells. Artifacts must be explicitly labeled so the model learns to ignore them.
- `RBC` (Red Blood Cell)
- `WBC` (White Blood Cell - can be sub-classed later)
- `platelet`
- `artifact` (sensor dust, scratches on the slide)
- `bubble` (air bubbles in the fluid)
- `debris` (unidentifiable biological matter)
- `unclear/ignore` (used by annotators when they cannot determine the class; the loss function should ignore these regions during training).

### 4. Handling Unlabeled & Image Quality Data
- **Unlabeled Data**: Kept in a separate directory for self-supervised pretraining (e.g., training a DINOv2 feature extractor).
- **Image Quality Labels**: A separate dataset containing whole-image labels: `sharp`, `blurry`, `overexposed`, `underexposed`, `empty`.

### 5. Locked Validation/Test Split
Data is split geographically/temporally (e.g., by slide, by cartridge, or by day), not randomly shuffled. Random shuffling leads to data leakage if adjacent stitched frames end up in both train and test sets.
The Test set is strictly locked and never used for hyperparameter tuning.

## Data Formats

- **Object Detection**: YOLO `.txt` format or COCO JSON.
- **Segmentation**: PNG Masks. We strictly separate detection labels from segmentation masks to allow training different models independently.

## Example Label Schema JSON (`label_schema.json`)

```json
{
  "version": "1.0",
  "classes": {
    "0": {"name": "RBC", "color": "#FF0000", "type": "polygon"},
    "1": {"name": "WBC", "color": "#00FF00", "type": "polygon"},
    "2": {"name": "platelet", "color": "#0000FF", "type": "polygon"},
    "3": {"name": "artifact", "color": "#FFFF00", "type": "bbox"},
    "4": {"name": "bubble", "color": "#00FFFF", "type": "polygon"},
    "5": {"name": "debris", "color": "#FF00FF", "type": "bbox"},
    "6": {"name": "unclear", "color": "#808080", "type": "polygon"}
  },
  "metadata_requirements": ["confidence", "source_type", "reviewer_id"]
}
```

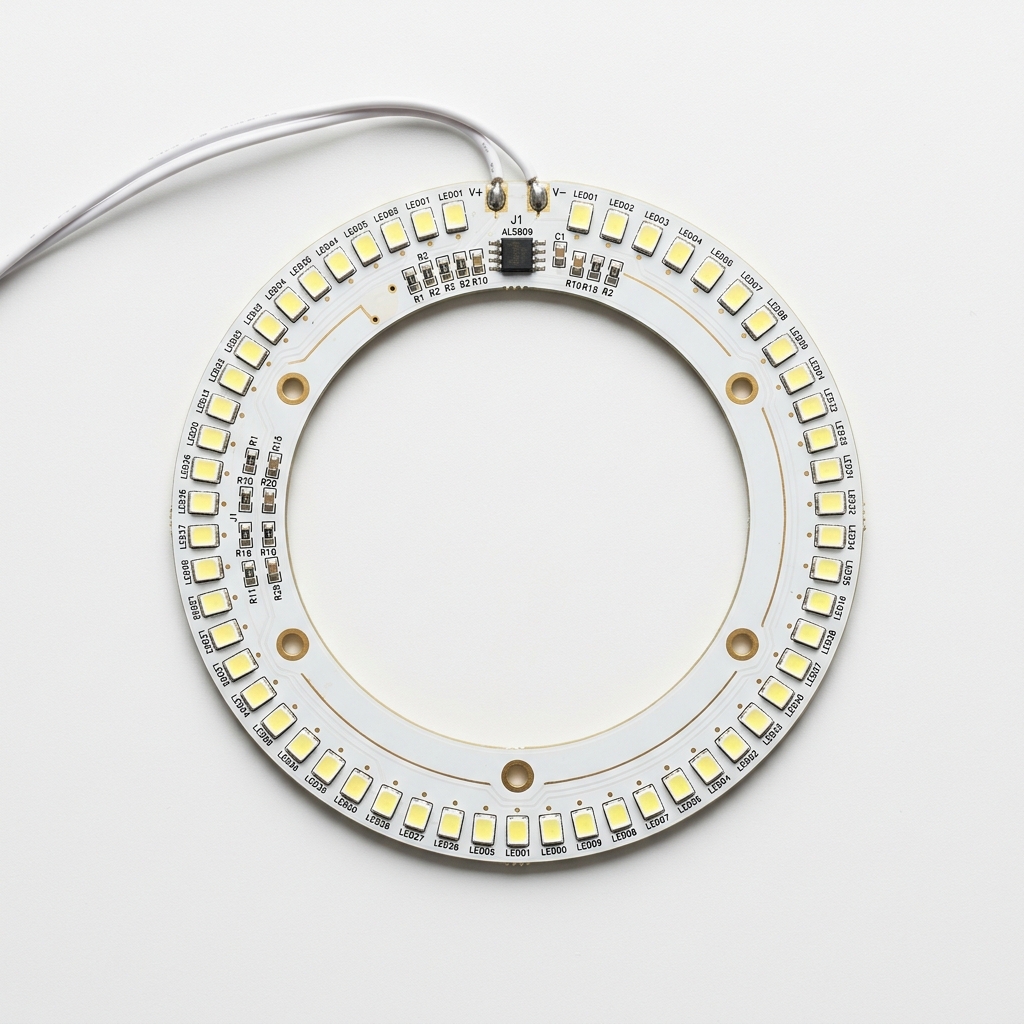
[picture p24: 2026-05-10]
design-docs/assets/images/hardware/prototype/led_ring.png

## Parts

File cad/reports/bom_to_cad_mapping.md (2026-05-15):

# BOM to CAD Mapping

| Bought part | Stage | CAD relationship |
| --- | --- | --- |
| Glass microscope slide | Stage 1 | Held by `cbc_slide_holder_r001`; uses a removable pocket, window, M3 holes, and retainer slots. |
| Raspberry Pi 4 | Stage 1 | Mounted by `cbc_pi4_mount_r001`; board envelope and hole span are locked, connector keepouts remain to verify. |
| Raspberry Pi Global Shutter Camera | Stage 1 | Mounted by `cbc_camera_mount_rpi_gs_r001`; board and hole pattern are locked, sensor-plane offset remains unresolved. |
| AmScope 40X RMS objective | Stage 1 placeholder | Represented by `cbc_objective_holder_placeholder_r001`; this is not a final RMS threaded holder. |
| Optical axis / sensor datum | Stage 1 | Represented by `cbc_optical_axis_datum_r001` for alignment only, not a printed manufacturing part. |
| InnovaMaker IMX296 camera | Stage 2 | Future alternate camera mount; actual board and sensor offset must be measured. |
| MGN12 rails/carriages | Stage 2 | Future XY-motion rail supports and carriages; exact holes remain unresolved. |
| T8 lead screws and nuts | Stage 2 | Future lead-nut carriers and knobs; nut body and hole pattern remain unresolved. |
| NEMA17 steppers | Stage 2 optional | Future motor mounts; shaft length and pilot boss geometry remain unresolved. |
| Raspberry Pi Pico | Stage 2 electronics | Board envelope locked; mount holes unresolved. |
| Adafruit TLC5947 | Stage 2 electronics | Board envelope locked; mount holes unresolved. |
| Adafruit Perma-Proto Quarter | Stage 2 electronics | Two-hole board policy dimensions locked; tray orientation/product ID must be verified. |
| M3 screws and heat-set inserts | Stage 1/2 | Clearance and pilot parameters are in `clearances.yaml`; insert pilot is insert-dependent and should be coupon-tested. |

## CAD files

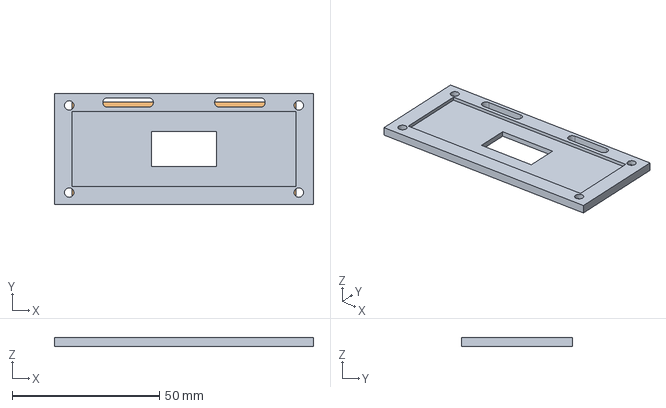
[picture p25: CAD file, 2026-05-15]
cad/exports/step/cbc_slide_holder_r001.step
88.0 x 37.6 x 3.00 mm

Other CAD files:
cad/exports/stl/cbc_slide_holder_r001.stl

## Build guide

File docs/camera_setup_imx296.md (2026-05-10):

# IMX296 Camera Setup

1. Ensure the FPC cable is connected to the CSI port on the Pi.
2. In `/boot/firmware/config.txt`, add:
   `dtoverlay=imx296`
3. Reboot.

## Testing the Hardware

Run the standard Raspberry Pi camera tools to ensure the driver is loaded properly:
```bash
rpicam-hello -t 5000
rpicam-still -o test.jpg
```

## Running the Application

Update the repository and start the server:
```bash
cd ~/cbc-scanner
git pull origin main
bash scripts/install_pi.sh
bash scripts/run_ui.sh
```

Then open the browser: `http://localhost:8000`

## API Testing

You can also test the integration directly via the REST API:
```bash
curl http://localhost:8000/api/devices/status
curl -X POST http://localhost:8000/api/camera/test
curl -X POST http://localhost:8000/api/capture/single
curl http://localhost:8000/api/scans
```

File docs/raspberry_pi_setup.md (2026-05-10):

# Raspberry Pi Setup

1. Flash standard Raspberry Pi OS (64-bit recommended)
2. Connect to WiFi
3. Enable SSH
4. Run the bootstrap script:
   `curl -fsSL https://raw.githubusercontent.com/OWNER/cbc-scanner/main/scripts/bootstrap_pi.sh | bash`
5. The system will handle the rest!

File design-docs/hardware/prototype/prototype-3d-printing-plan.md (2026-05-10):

# 3D Printing Plan

## 1. Purpose
This document outlines the engineering plan for fabricating the prototype chassis using Fused Deposition Modeling (FDM) 3D printing. The goal is to produce rigid, accurate parts that maintain optical alignment while allowing rapid iteration.

## 2. Printing Strategy
- **Rigidity over speed**: Print with higher wall counts rather than high infill.
- **Optical considerations**: Use matte black materials for any parts near the optical path to reduce stray light reflections.
- **Modularity**: Design parts to bolt together rather than printing massive single unibodies. This reduces print failure risk and allows replacing single brackets.

## 3. Printer/Material Assumptions
- Standard FDM printer (e.g., Prusa i3, Bambu Lab, Ender 3).
- 0.4mm nozzle.
- Textured or smooth PEI build plate.

## 4. Material Selection
- **PLA**: Acceptable for the first, quick prototype. It is stiff and easy to print.
- **PETG**: Recommended for parts near the LEDs or motors, as PLA will deform under heat.
- **ABS/ASA**: Best for long-term prototypes due to high heat deflection, but harder to print without an enclosure.
- **Matte Black PLA/PETG**: Strongly preferred for the optical tower and lens mounts. Flocking material or matte black paint can be applied post-print if standard shiny filament is used.

## 5. Print Settings
- **Layer Height**: 0.2mm (standard). Use 0.12mm for fine threaded parts if not using metal inserts.
- **Wall Count (Perimeters)**: Minimum 4 walls. This is where the part gets its strength.
- **Infill**: 20% - 40% Gyroid or Cubic.
- **Supports**: Avoid where possible. Orient parts so critical mounting holes print cleanly.

## 6. Printable Parts Breakdown

| Part | Preview | STL/CAD Link | Material & Print Settings | Orientation | Notes |
| :--- | :--- | :--- | :--- | :--- | :--- |
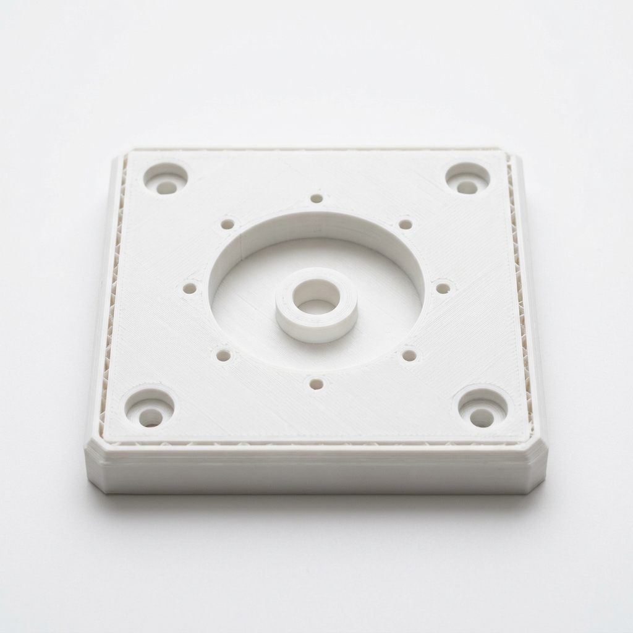
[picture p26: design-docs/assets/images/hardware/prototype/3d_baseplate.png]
| Baseplate |  | Custom CAD required | PETG, 25% infill, 4 walls | Flat | **Main foundation**. Heavy and rigid. Hardware: M3 inserts |
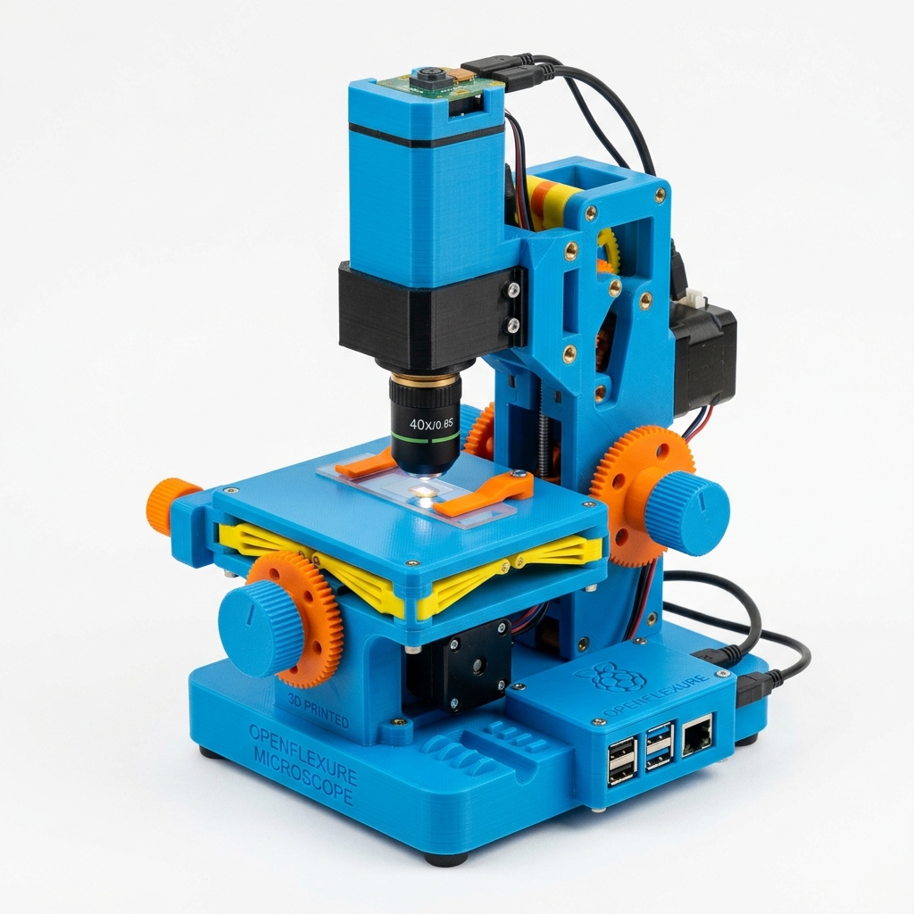
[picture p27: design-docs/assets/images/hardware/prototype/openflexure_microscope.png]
| Optical Tower |  | [OpenFlexure v7 Base](https://openflexure.org/projects/microscope/build) | Black PETG, 40% infill, 5 walls | Vertical | **Z-axis support**. Use as reference design. Hardware: M3 screws |
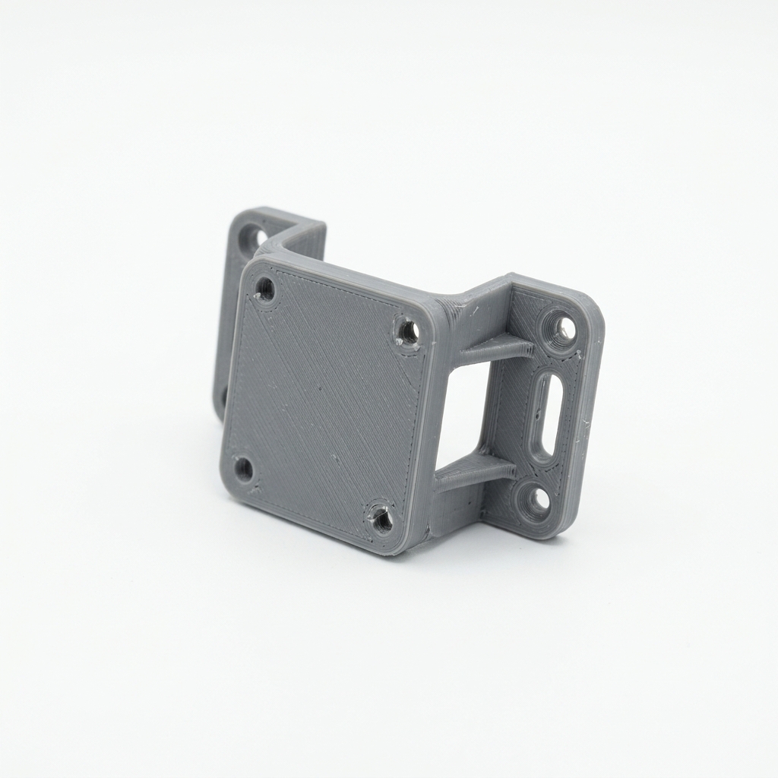
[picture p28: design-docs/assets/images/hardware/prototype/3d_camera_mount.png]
| Camera Mount |  | [Raspberry Pi HQ Mount](https://www.thingiverse.com/thing:4357597) | PETG, 30% infill, 4 walls | Flat | **Holds IMX296**. Modify for IMX296 hole spacing. Hardware: M2.5 screws |
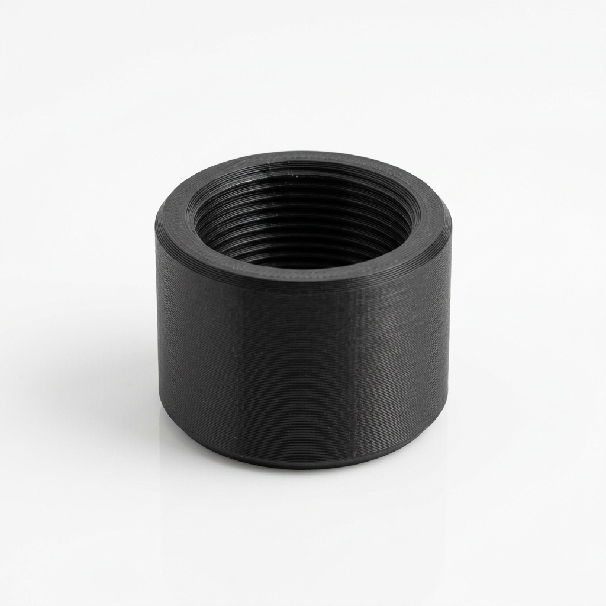
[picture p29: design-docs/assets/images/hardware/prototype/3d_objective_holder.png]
| Objective Holder |  | [RMS to C-mount adapter](https://www.thingiverse.com/thing:2988173) | Black PETG, 50% infill, 5 walls | Flat | **Holds RMS lens**. Thread tolerances are critical. May need 0.12mm layers. Hardware: None |
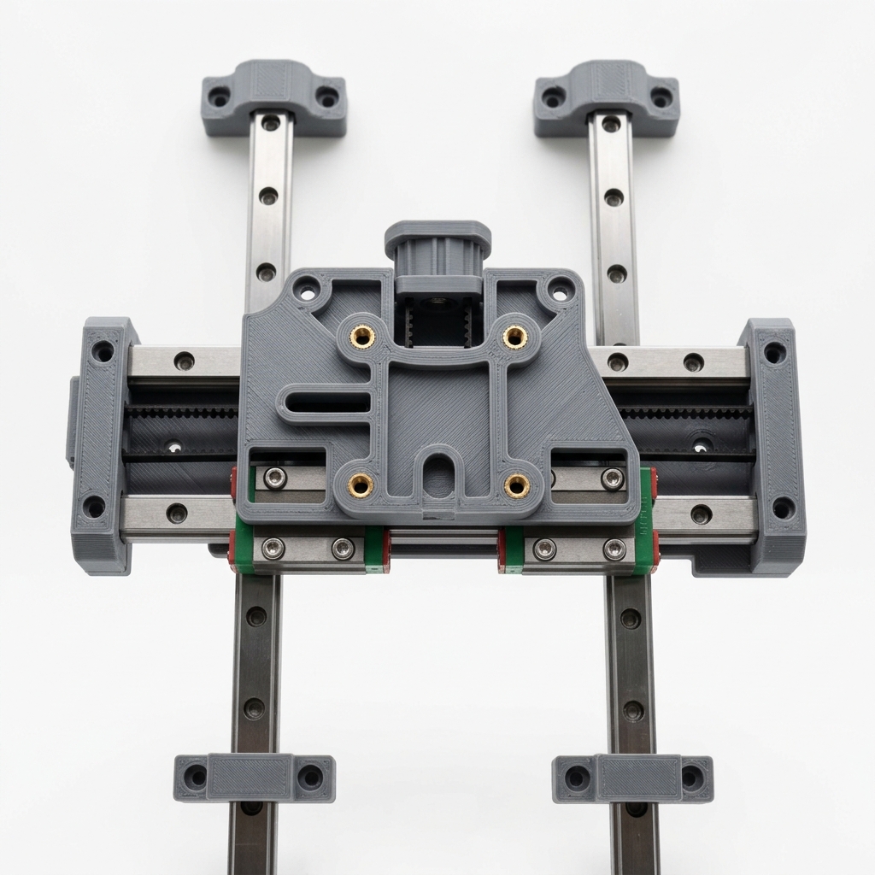
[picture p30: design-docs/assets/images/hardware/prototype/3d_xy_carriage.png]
| XY Carriage |  | Custom CAD required | PLA/PETG, 30% infill, 4 walls | Flat | **Moves sample**. Must mount to linear rails. Hardware: MGN12 blocks |
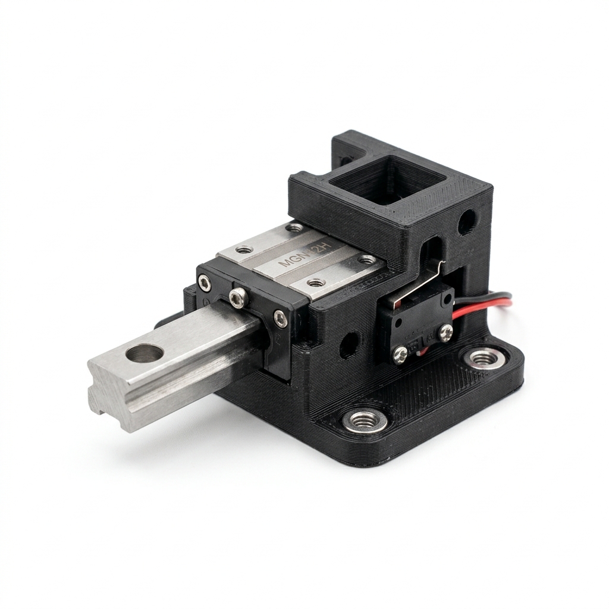
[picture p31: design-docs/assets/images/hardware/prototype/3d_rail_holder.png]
| Rail Holders |  | Custom CAD required | PETG, 40% infill, 4 walls | Flat | **Secures MGN12**. . Hardware: M3 screws |
| Lead Nut Mount |  | Custom CAD required | PETG, 30% infill, 4 walls | Flat | **Drives XY**. . Hardware: Anti-backlash nut |
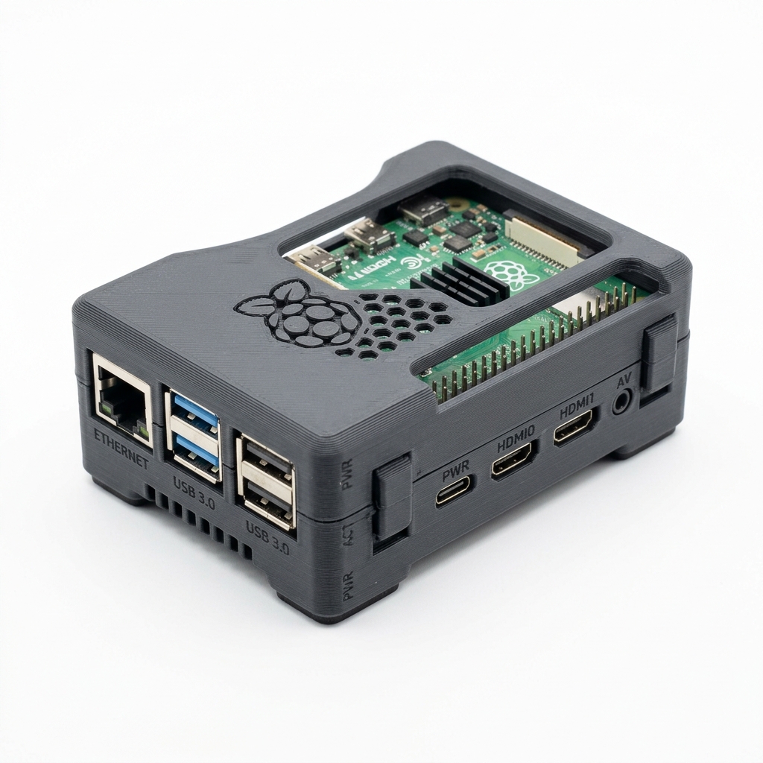
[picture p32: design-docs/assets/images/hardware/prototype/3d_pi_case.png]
| Pi Case/Mount |  | [RPi 4 Snap-fit Case](https://www.printables.com/model/4074-raspberry-pi-4-snap-fit-case) | PLA, 20% infill, 3 walls | Flat | **Holds RPi**. . Hardware: None |

## 7. Parts Not Suitable for Printing
- Precision linear rails (MGN12).
- Lead screws and nuts.
- Bearings.
- Optical lenses.
**Rule:** Avoid plastic-on-plastic sliding for anything requiring repeatable movement (like the XY stage). It causes stiction and backlash.

## 8. Downloadable STL/CAD Options
We leverage open-source designs where possible:
- **OpenFlexure Microscope**: Excellent reference for 3D printed flexure mechanisms if we decide to avoid linear rails for the Z-axis. [View Project](https://openflexure.org/)
  <br>
- **UC2 Modular Microscopy**: Great reference for magnetic, modular optical cubes. [View GitHub](https://github.com/openUC2/UC2-GIT)
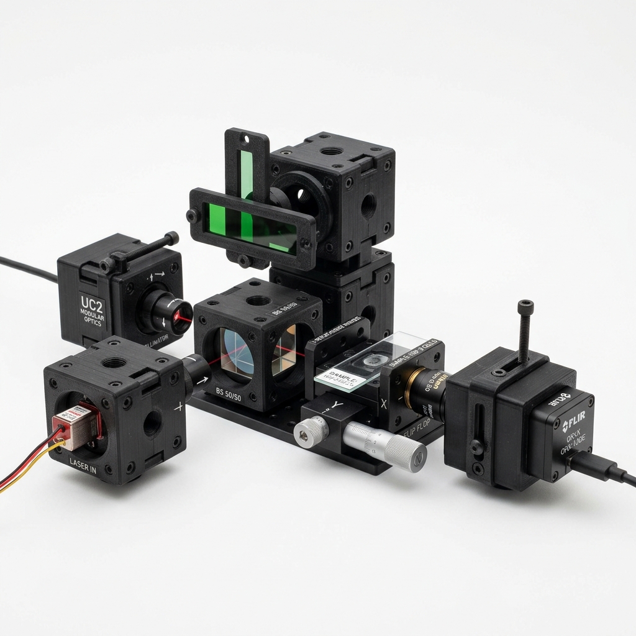
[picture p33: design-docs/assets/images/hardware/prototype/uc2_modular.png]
  <br>

## 9. Tolerance and Fit Guidance
- Add **0.2 mm to 0.4 mm** clearance to CAD dimensions for printed fits (e.g., a peg going into a hole).
- Holes intended for M3 screws to pass through freely should be modeled at **3.2mm - 3.4mm**.
- Holes for heat-set inserts should be sized according to the insert manufacturer's spec (typically ~4.0mm diameter for an M3 insert).
- Use chamfers (not fillets) for overhangs near the build plate to prevent elephant's foot from ruining tolerances.

## 10. Heat-Set Insert Guidance
Use M3 heat-set inserts (like those from CNC Kitchen) for parts that will be repeatedly assembled/disassembled. Press them in using a soldering iron set to the melting temperature of the filament (e.g., 200°C for PLA).

## 11. Part Versioning
Append a version number to all exported STLs: `XY_Carriage_v1.2.stl`. Store them in `design-docs/assets/stl/`.

## 12. Quality Checklist
- [ ] No stringing or blobs inside the optical path.
- [ ] Dimensions measure within 0.1mm of CAD using calipers.
- [ ] M3 screws pass through clearance holes freely.
- [ ] Heat set inserts sit flush with the surface.

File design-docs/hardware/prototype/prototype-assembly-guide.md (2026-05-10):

# Prototype Assembly Guide

This guide details the step-by-step process for assembling the CBC multispectral prototype.

## Tools Required
- Hex/Allen key set (Metric, 1.5mm to 3mm).
- Soldering iron (with heat-set insert tip).
- Small Phillips screwdriver.
- Digital calipers.
- Flush cutters (for cleaning prints).

## Fasteners Required
- M3 socket head cap screws (various lengths: 6mm, 8mm, 12mm, 20mm).
- M3 heat-set inserts.
- M2.5 screws (for Raspberry Pi mounting).

## Safety Notes
- Unplug power before wiring the LED driver or Raspberry Pi.
- Be careful with the soldering iron when pressing inserts.
- Do not touch the glass surface of the objective lens or the bare IMX296 sensor.

## Step-by-Step Assembly

### 1. Preparation
- **Print and inspect parts**: Ensure all 3D printed parts are clean and free of stringing. Ream out clearance holes with a 3mm drill bit if necessary.
- **Install heat-set inserts**: Use the soldering iron to press M3 inserts into the designated holes on the baseplate, optical tower, and carriage. Let them cool.

### 2. Base and Optics
- **Assemble base**: Attach rubber feet to the baseplate.
- **Mount vertical optical tower**: Bolt the Z-axis tower securely to the baseplate. Ensure it is perfectly perpendicular.
- **Mount camera**: Attach the IMX296 camera board to the printed camera mount using M2.5 screws. Attach this mount to the top of the optical tower.
- **Mount lens/objective**: Carefully thread the AmScope 40X objective into the printed RMS holder.
- **Align optical axis**: Ensure the camera sensor is centered directly above the objective lens. If using a 160mm objective, use calipers to verify the distance from the objective shoulder to the camera sensor is exactly 160mm.

### 3. Stage and Illumination
- **Mount LED/diffuser**: Assemble the LED ring and the diffuser plate. Mount this directly below the objective lens on the baseplate.
- **Assemble XY stage**:
    - Attach the MGN12 linear rails to the baseplate (X-axis).
    - Attach the Y-axis rails to the intermediate carriage.
    - Attach the slide holder top plate.
    - Thread the T8 lead screws through the anti-backlash nuts and attach the manual knobs.
- **Install slide holder**: Verify the slide clamps securely hold a standard 25x75mm glass slide.
- **Check movement**: Manually turn the X and Y knobs. The stage should move smoothly without binding.

### 4. Electronics
- **Mount Raspberry Pi**: Attach the Pi to its case/mount on the side of the chassis.
- **Wire LED**: Connect the LED ring to its power supply or driver board.
- **Connect camera ribbon**: Carefully insert the MIPI ribbon cable into the Pi's camera port and the IMX296 board. Ensure the silver contacts face the correct direction.

### 5. Testing and Validation
- **Boot Pi**: Connect power to the Raspberry Pi. Wait for it to boot.
- **Run camera test**: Open an SSH terminal and run `libcamera-hello` or `rpicam-hello` to verify the sensor is detected.
- **LED test**: Turn on the LED array and verify uniform illumination through the diffuser.
- **Capture first focused image**:
    - Place the calibration slide on the stage.
    - Run a continuous preview (`libcamera-vid -t 0`).
    - Adjust the Z-focus knob until the grid lines are sharp.
    - Save the image.
- **Capture 5 to 10 overlapping images**:
    - Move the X/Y knobs to pan across the slide.
    - Capture an image, move the stage so the next view overlaps by ~50%, capture again. Repeat for a 3x3 grid.
- **Stitching test**: Run the offline Python stitching script on the captured grid. Verify successful alignment.

## Troubleshooting Table

| Symptom | Likely Cause | Fix |
| :--- | :--- | :--- |
| Camera not detected | Ribbon cable upside down or loose | Re-seat cable at both ends; check Pi OS configuration |
| Image is completely black | LED off, or objective extremely out of focus | Turn on LED; move Z-axis significantly until light is visible |
| Image is blurry / won't focus | Distance from lens to sensor is incorrect | Adjust Z-axis position; verify 160mm tube length |
| Image is unevenly lit | Diffuser missing or misaligned | Add diffuser; center LED under objective |
| XY stage binds or stutters | Linear rails misaligned | Loosen rail screws, move carriage back and forth to self-align, retighten |
| Stitching fails | Insufficient overlap or out of focus | Ensure >40% overlap; ensure slide is perfectly flat relative to XY travel |

## Pass/Fail Checklist
| Assembly Step | Expected Result | Pass/Fail |
| :--- | :--- | :--- |
| Mechanical | Frame is rigid, no loose parts | [ ] |
| Motion | Stage moves smoothly across full travel | [ ] |
| Electronic | Pi boots, Camera streams preview | [ ] |
| Optical | Can achieve sharp focus on a slide | [ ] |
| Pipeline | Can stitch 5 manual images | [ ] |

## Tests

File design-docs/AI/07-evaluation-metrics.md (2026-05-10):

# Evaluation Metrics

This document defines the statistical metrics used to evaluate the performance of the AI and CV pipelines.

## Detection Metrics
Evaluated on bounding box predictions (e.g., YOLO output).
- **Precision**: True Positives / (True Positives + False Positives). How many of the predicted cells are actually cells?
- **Recall**: True Positives / (True Positives + False Negatives). How many of the actual cells did we find?
- **mAP50**: Mean Average Precision at an Intersection over Union (IoU) threshold of 0.50. The primary metric for general detection capability.
- **mAP50-95**: Mean Average Precision averaged across IoU thresholds from 0.50 to 0.95. A strict metric that evaluates how perfectly the bounding box aligns with the object.

## Segmentation Metrics
Evaluated on pixel-perfect masks (e.g., U-Net output).
- **IoU (Intersection over Union) / Jaccard Index**: Area of Overlap / Area of Union between the predicted mask and ground truth mask.
- **Dice Coefficient (F1 Score for pixels)**: `2 * |Intersection| / (|Predicted| + |GroundTruth|)`. Highly correlated with IoU but penalizes false positives/negatives differently.
- **Boundary Quality**: Metrics evaluating the distance between the predicted contour and the ground truth contour, crucial for tightly clumped cells.

## Counting Metrics
The ultimate goal of the system is an accurate count, even if segmentation isn't perfect.
- **Absolute Count Error**: `|Predicted Count - Actual Count|` per image or per scan.
- **Percent Count Error**: `(|Predicted Count - Actual Count| / Actual Count) * 100`.
- **Mean Absolute Error (MAE)**: Average of the Absolute Count Errors across the test dataset.
- **Bland-Altman Analysis**: To be implemented later for reference comparison against clinical gold-standard hematology analyzers.

## Quality Control Metrics
Evaluates the robustness of the automated pipeline.
- **Bad Image Rejection Rate**: The percentage of truly bad images successfully caught and rejected by the CV focus/brightness checks.
- **False Rejection Rate**: The percentage of perfectly good images incorrectly flagged as bad.
- **CV/AI Disagreement Rate**: How often the classical CV pipeline and the Neural Network disagree on the count by more than a set threshold (e.g., 10%).
- **Stitching Success Rate**: Percentage of scans where the 5-10 overlapping images were successfully aligned into a mosaic without fatal errors.

## Dataset & Operations Metrics
- **Label Review Rate**: How many images are being sent to the human review queue per day.
- **Pseudo-label Acceptance Rate**: How often a human reviewer accepts an AI-generated pseudo-label without modification.
- **Class Imbalance**: Tracking the ratio of RBCs to WBCs to platelets in the training set to ensure minority classes are sampled correctly.

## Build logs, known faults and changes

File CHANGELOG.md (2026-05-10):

# Changelog

All notable changes to this project will be documented in this file.

The format is based on [Keep a Changelog](https://keepachangelog.com/en/1.0.0/),
and this project adheres to [Semantic Versioning](https://semver.org/spec/v2.0.0.html).

## [0.1.0] - Initial Release
### Added
- Repository initialization.
- FastAPI backend with initial API routes.
- Hardware Abstraction Layers for cameras, stages, and lights.
- Mock implementations of devices for development.
- Picamera2 IMX296 driver implementation.
- Installer and bootstrapper scripts for Raspberry Pi.
- React, Vite, Tailwind CSS frontend dashboard.

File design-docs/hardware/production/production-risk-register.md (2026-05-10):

# Production Risk Register

This document tracks anticipated risks in transitioning from prototype to production hardware and deploying the device at scale.

| Risk | Likelihood | Impact | Affected Subsystem | Mitigation | Status |
| :--- | :--- | :--- | :--- | :--- | :--- |
| **Blurry images from vibration** | High | High | Optics/Focus | Implement robust autofocus algorithm; ensure Z-axis rigidity; use vibration-dampening feet. | Open |
| **Poor focus repeatability** | Medium | High | Motion (Z) | Use high-precision lead screw and closed-loop control; switch to machined metal mounts. | Open |
| **Stage backlash ruining stitching** | High | Medium | Motion (XY) | Use pre-loaded linear rails (Z1 preload) and anti-backlash nuts; implement software backlash compensation. | Open |
| **Uneven illumination (vignetting)**| Medium | Medium | Illumination | Calibrate LED array; use high-quality diffuser; implement software flat-field correction. | Open |
| **LED intensity degradation** | Medium | High | Illumination | Implement closed-loop photodiode feedback to maintain constant lux over the device lifespan. | Open |
| **Misaligned multispectral images** | Medium | High | Optics/Capture | Ensure extremely rigid camera mount; implement software-based phase correlation alignment. | Open |
| **Public dataset mismatch** | High | Medium | AI Pipeline | Extensive fine-tuning on device-specific data; use color augmentation during pretraining. | Open |
| **Poor segmentation on device images**| Medium | High | AI/CV Pipeline | Implement an active learning loop; enforce human review of edge cases and low-confidence predictions. | Open |
| **Stitching failure** | Low | High | Software/Motion | Ensure 40-60% overlap hardware capability; improve feature extraction algorithms (SIFT/ORB). | Open |
| **Cartridge optical distortion** | Medium | High | Sample/Cartridge | Work closely with medical plastics manufacturer to control material clarity and chamber depth tolerance. | Open |
| **Dust/debris false positives** | High | Medium | AI/CV Pipeline | Design a sealed optical enclosure; implement software filtering of static artifacts using background subtraction. | Open |
| **Production tolerance issues** | Medium | Medium | Manufacturing | Define strict GD&T tolerances for critical optical mounts and linear rail mating surfaces. | Open |

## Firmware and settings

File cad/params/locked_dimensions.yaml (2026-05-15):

locked_dimensions:
  system:
    max_footprint_x_mm: 200.0
    max_footprint_y_mm: 200.0
    max_height_mm: 300.0
    stage1_baseplate_x_mm: 180.0
    stage1_baseplate_y_mm: 160.0
    stage1_baseplate_z_mm: 6.0
    stage1_baseplate_corner_radius_mm: 8.0
    rubber_foot_offset_from_corner_mm: 12.0
  optics:
    objective_nominal_mag: 40.0
    objective_mount_standard: RMS
    objective_rms_major_diameter_in: 0.8
    objective_rms_tpi: 36
    objective_shoulder_to_sensor_plane_mm: 160.0
    stage1_placeholder_objective_outer_d_mm: 25.0
    stage1_placeholder_holder_bore_mm: 26.0
    stage1_placeholder_holder_wall_mm: 4.0
  slide:
    slide_x_mm: 75.0
    slide_y_mm: 25.0
    pocket_x_mm: 76.0
    pocket_y_mm: 25.6
    viewing_window_x_mm: 22.0
    viewing_window_y_mm: 12.0
    holder_z_mm: 3.0
  camera_rpi_gs:
    sensor_resolution_x_px: 1456
    sensor_resolution_y_px: 1088
    pixel_pitch_um: 3.45
    board_x_mm: 38.0
    board_y_mm: 38.0
    board_nest_x_mm: 38.5
    board_nest_y_mm: 38.5
    mount_hole_dia_mm: 2.5
    mount_hole_span_x_mm: 30.0
    mount_hole_span_y_mm: 30.0
  pi4:
    board_x_mm: 85.0
    board_y_mm: 56.0
    board_nest_x_mm: 85.5
    board_nest_y_mm: 56.5
    mount_hole_span_x_mm: 58.0
    mount_hole_span_y_mm: 49.0
    mount_hole_dia_mm: 2.7
    standoff_boss_outer_d_mm: 7.0
    standoff_boss_height_mm: 5.0
    standoff_hole_d_mm: 2.8
  pico:
    board_x_mm: 51.3
    board_y_mm: 21.0
    board_z_mm: 3.9
  tlc5947:
    board_x_mm: 51.1
    board_y_mm: 25.39
    board_z_mm: 4.0
  permaproto_quarter:
    board_x_mm: 50.8
    board_y_mm: 43.0
    board_z_mm: 1.6
    mount_hole_dia_mm: 3.2
    mount_hole_span_x_mm: 35.56
  nema17_pololu_2267:
    face_x_mm: 42.3
    face_y_mm: 42.3
    body_length_mm: 38.0
    shaft_d_mm: 5.0
    motor_mount_span_x_mm: 31.0
    motor_mount_span_y_mm: 31.0

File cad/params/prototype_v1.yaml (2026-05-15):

prototype_v1:
  revision: r001
  material_tags:
    optics_adjacent: matte_black_petg
    motion_structural: petg
    electronics_mounts: petg_or_pla
    coupons: target_material_required
  layout:
    baseplate_x_mm: 190.0
    baseplate_y_mm: 180.0
    baseplate_z_mm: 8.0
    optical_axis_x_mm: 0.0
    optical_axis_y_mm: 20.0
    tower_height_mm: 220.0
    tower_offset_y_mm: 65.0
    rail_support_height_mm: 16.0
    carriage_plate_z_mm: 6.0
    electronics_deck_x_mm: 92.0
    electronics_deck_y_mm: 72.0
  stage1:
    revision: r001
    optical_axis_x_mm: 0.0
    optical_axis_y_mm: 12.0
    slide_holder_mount_span_x_mm: 88.0
    slide_holder_mount_span_y_mm: 38.0
    tower_mount_span_x_mm: 48.0
    tower_mount_span_y_mm: 24.0
    pi_mount_center_x_mm: 42.0
    pi_mount_center_y_mm: -42.0
    camera_plate_z_mm: 4.0
    objective_holder_height_mm: 18.0
  optics:
    objective_holder_outer_d_mm: 34.0
    objective_holder_height_mm: 18.0
    optical_tube_outer_d_mm: 38.0
    optical_tube_wall_mm: 3.0
    camera_mount_face_to_sensor_plane_mm: 5.0
    led_ring_outer_d_mm: 70.0
    led_ring_inner_d_mm: 32.0
    led_count: 16
    diffuser_frame_x_mm: 72.0
    diffuser_frame_y_mm: 72.0
    diffuser_window_d_mm: 42.0
  motion:
    nominal_travel_x_mm: 70.0
    nominal_travel_y_mm: 35.0
    rail_support_x_mm: 88.0
    rail_support_y_mm: 18.0
    rail_support_z_mm: 16.0
    x_carriage_x_mm: 86.0
    x_carriage_y_mm: 54.0
    y_carriage_x_mm: 92.0
    y_carriage_y_mm: 42.0
    lead_nut_carrier_x_mm: 34.0
    lead_nut_carrier_y_mm: 24.0
    lead_nut_carrier_z_mm: 16.0
    manual_knob_d_mm: 34.0
    manual_knob_z_mm: 14.0
  electronics:
    standoff_height_mm: 6.0
    tray_wall_mm: 2.0
    tray_floor_mm: 2.5
  exports:
    part_revision: r001

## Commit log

2026-05-10 Initial commit of cbc-scanner
    [future_microcontroller.yaml]
2026-05-10 Fix uv PATH setup in Raspberry Pi bootstrap
2026-05-10 Improve CBC design docs with detailed hardware and AI plans
    [dataset-sources.csv, image-sources.csv, product-sources.csv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]
2026-05-10 Update README with folder details, download hardware component images
    [image-sources.csv]
2026-05-10 Fix image rendering in prototype product list
2026-05-10 Add remaining inline BOM images and CAD links
2026-05-10 Simplify BOM table to fix GitHub horizontal scrolling issue
2026-05-10 Add 3D part preview images and update BOM with direct product links
2026-05-10 Update prototype product list with multispectral LED BOM
2026-05-10 Fix broken Amazon and Mouser links, switch to Digikey and search queries
2026-05-11 Found 3 new datasets
    [dataset-sources.csv]
2026-05-11 Added 3 new dataset with notes on why they matter
    [dataset-sources.csv]
2026-05-15 Add CBC prototype CAD system
    [cbc_baseplate_r001.step, cbc_baseplate_r001.stl, cbc_cable_clip_r001.step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]
2026-05-15 Add real Fusion slide holder CAD workflow
    [cbc_baseplate_r001.step, cbc_baseplate_r001.stl, cbc_cable_clip_r001.step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]
2026-05-15 Fix Stage 1 CAD workflow packaging
    [locked_dimensions.yaml]
